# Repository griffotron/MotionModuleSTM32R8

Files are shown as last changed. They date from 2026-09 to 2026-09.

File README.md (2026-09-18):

# Introduction 
This repository contains the PCB design files and source code for the STM32 based Motion Module used in my Mechanical Display.

The Motion Module uses an STM32F103R8 microcontroller to run 14 Trinamic TMC2209 stepper drivers. It recieves motor movement commands via CAN Bus from the ESP32 based Motion Controller. Please see the related repos for the [ESP32 Controller](https://github.com/griffotron/MotionControllerESP32) and [CAD Designs](https://github.com/griffotron/MechanicalDisplayCAD).

# Build Video
Click below to watch the full build video on YouTube
Watch the video (https://www.youtube.com/watch?v=k-LaMbClWiI)

# Getting Started

## PCB
You'll need at least KiCad 8 to view and modify the PCB design files. The `PCB/production` folder contains files suitable for production with JLC PCB, including a zip containing the Gerbers for fabrication and `bom.csv` and `positions.csv` for SMT assembly. The `bom.csv` uses components from LCSC.com. If any components are no longer be available/out of stock you'll need to select an alternative.

## Code
The code uses PlatformIO (I used the VSCode plugin) and the Arduino framework.

CAN Bus library is from https://github.com/pazi88/CANBus

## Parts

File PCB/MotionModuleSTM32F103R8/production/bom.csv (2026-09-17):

Designator | Footprint | Quantity | Value | LCSC Part #
C1, C10, C101, C103, C106, C107, C109, C11, C111, C114, C115, C117, C119, C12, C122, C123, C125, C127, C13, C18, C19, C21, C23, C26, C27, C29, C31, C34, C35, C37, C39, C42, C43, C45, C47, C5, C50, C51, C53, C55, C58, C59, C61, C63, C66, C67, C69, C7, C71, C74, C75, C77, C79, C8, C82, C83, C85, C87, C9, C90, C91, C93, C95, C98, C99 | 0603 | 65 | 0.1u 50V | C14663
C100, C108, C116, C124, C20, C28, C36, C44, C52, C60, C68, C76, C84, C92 | 0603 | 14 | 22n 50V | C21122
C102, C110, C118, C126, C22, C30, C38, C46, C54, C6, C62, C70, C78, C86, C94 | 0603 | 15 | 4.7u 10v | C19666
C104, C105, C112, C113, C120, C121, C16, C17, C24, C25, C32, C33, C40, C41, C48, C49, C56, C57, C64, C65, C72, C73, C80, C81, C88, C89, C96, C97 | 0603 | 28 | 10u 35V | C96446
C128, C129, C130, C131, C132, C133, C134, C135, C136, C137, C138, C139, C140, C141, C2 | CP_Elec_5x5.4 | 15 | 47u | C4747958
C14, C15 | 0603 | 2 | 30pf | C1658
C3 | CP_Elec_6.3x4.9 | 1 | 100u | C22395169
C4 | CP_Elec_4x5.7 | 1 | 10u | C5155338
D1 | 0603 | 1 | 12v PWR LED | C5179611
D2 | 0603 | 1 | 3.3v PWR LED | C5355429
D3 | 0603 | 1 | STATUS LED | C19171301
J1, J22 | PinHeader_1x02_P2.54mm_Vertical | 2 | Screw_Terminal_01x02
J10, J12, J14, J16, J18, J20, J23, J24, J25, J27, J29, J4, J6, J8 | PinHeader_1x04_P2.54mm_Vertical | 14 | Conn_01x04_Pin
J11, J13, J15, J17, J19, J21, J26, J28, J3, J30, J32, J5, J7, J9 | JST_PH_B4B-PH-K_1x04_P2.00mm_Vertical | 14 | Conn_01x04_Pin | C131334
J2 | PinHeader_1x05_P2.54mm_Vertical | 1 | Conn_01x05_Pin
R1 | 0603 | 1 | 2k | C22975
R10, R11, R12, R13, R14, R15, R16, R17, R18, R19, R20, R21, R22, R23, R24, R25, R26, R27, R28, R29, R30, R31, R32, R5, R6, R7, R8, R9 | 1206 | 28 | 0R11 | C309533
R2, R4 | 0603 | 2 | 500 | C23193
R3 | 0603 | 1 | 10k | C25804
R33, R34, R35, R36, R37, R38, R39, R40, R41, R42, R43, R44, R45, R46 | 0603 | 14 | R
SW1 | SW_Tactile_SPST_NO_Straight_CK_PTS636Sx25SMTRLFS | 1 | RESET | C2689642
TP1 | TestPoint_Pad_D2.0mm | 1 | BOOT0 TP
TP16 | TestPoint_Pad_D2.0mm | 1 | MS1
TP2 | TestPoint_Pad_D2.0mm | 1 | MS2
TP30 | TestPoint_Pad_D2.0mm | 1 | DIAG
TP44 | TestPoint_Pad_D2.0mm | 1 | UART
TP58 | TestPoint_Pad_D2.0mm | 1 | INDEX
U1 | SOT-223-3_TabPin2 | 1 | AMS1117-3.3 | C5250992
U10, U11, U12, U13, U14, U15, U16, U17, U4, U5, U6, U7, U8, U9 | QFN28_5X5_TRI | 14 | TMC2209 | C465949
U2 | SOIC-8_3.9x4.9mm_P1.27mm | 1 | MCP2562-E-SN | C191417
U3 | LQFP-64_10x10mm_P0.5mm | 1 | STM32F103R8Tx | C46034
Y1 | Crystal_SMD_5032-2Pin_5.0x3.2mm | 1 | Crystal | C115962

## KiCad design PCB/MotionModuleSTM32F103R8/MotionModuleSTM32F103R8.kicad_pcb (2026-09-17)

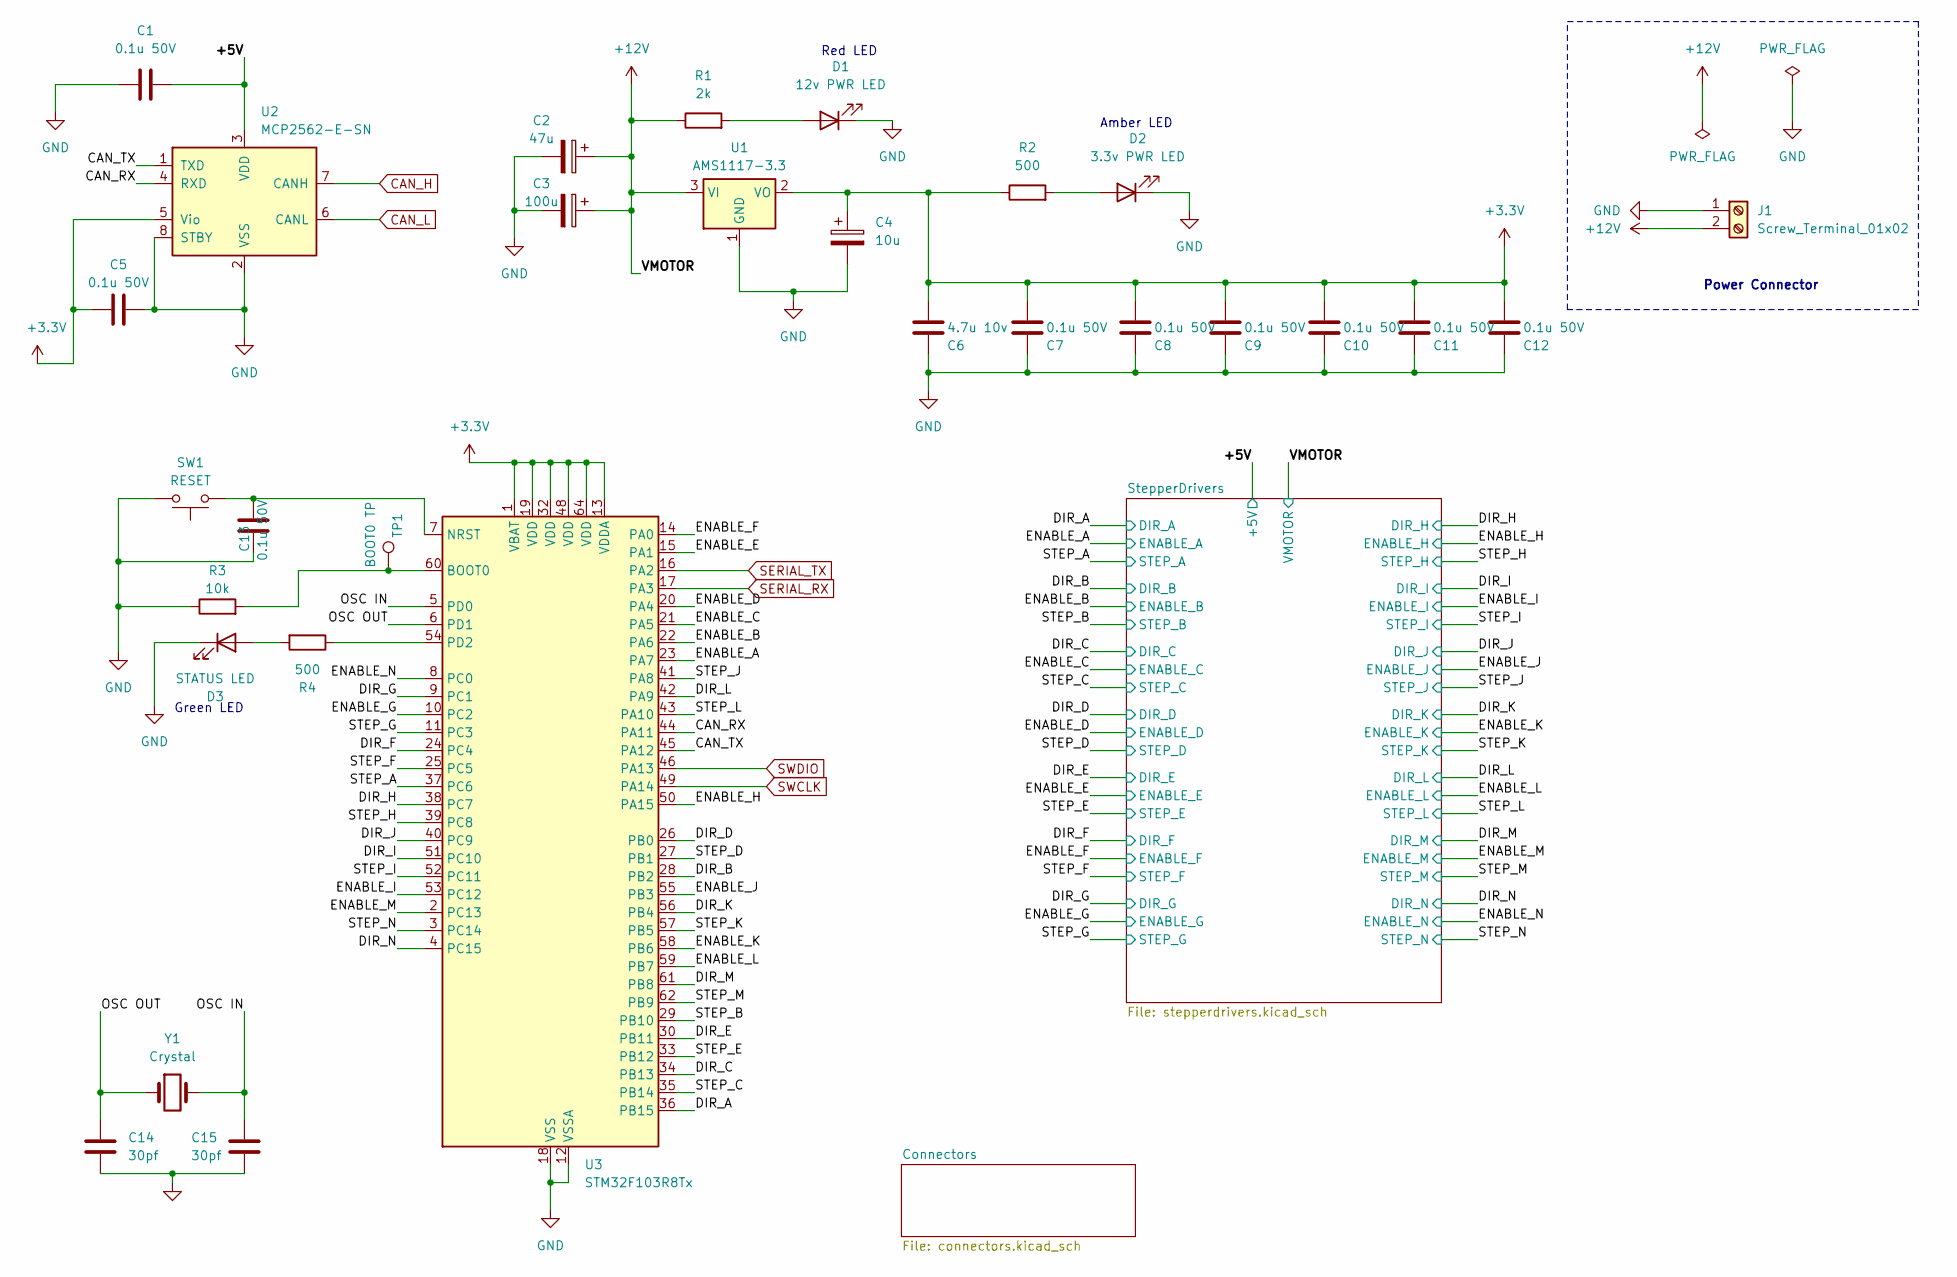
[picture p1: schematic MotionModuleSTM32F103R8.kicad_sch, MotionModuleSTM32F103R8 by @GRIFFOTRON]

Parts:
C1, C5, C7, C8, C9, C10, C11, C12, C13: 0.1u 50V; C_0603_1608Metric; MPN CC0603KRX7R9BB104; LCSC C14663
C2: 47u; CP_Elec_5x5.4; MPN RST47UF25V035; LCSC C4747958
C3: 100u; CP_Elec_6.3x4.9; MPN SPT1EM101E05TRVZC; LCSC C22395169
C4: 10u; CP_Elec_4x5.7; MPN FZ10UF25V90RV0144; DigiKey 732-6401-1-ND (Poly)
C6: 4.7u 10v; C_0603_1608Metric; MPN CL10A475KO8NNNC; LCSC C19666
C14, C15: 30pf; C_0603_1608Metric; MPN 0603CG300J500NT; LCSC C1658
D1: 12v PWR LED; LED_0603_1608Metric; MPN A-SP192YR6C-A02-4T; DigiKey 732-4978-1-ND
D2: 3.3v PWR LED; LED_0603_1608Metric; MPN A-SP192GS1C-A01-4T; DigiKey 732-150060AS75000CT-ND
D3: STATUS LED; LED_0603_1608Metric; MPN A-SP192DGHC-C01-4T; DigiKey 732-4971-1-ND
J1: Screw_Terminal_01x02; PinHeader_1x02_P2.54mm_Vertical
R1: 2k; R_0603_1608Metric; MPN 0603WAF2001T5E; LCSC C22975
R2, R4: 500; R_0603_1608Metric; MPN 0603WAF5100T5E; LCSC C23193
R3: 10k; R_0603_1608Metric; MPN 0603WAF1002T5E; LCSC C25804
SW1: RESET; SW_Tactile_SPST_NO_Straight_CK_PTS636Sx25SMTRLFS; MPN PTS636SK25SMTRLFS; LCSC C2689642
TP1: BOOT0 TP; TestPoint_Pad_D2.0mm
U1: AMS1117-3.3; SOT-223-3_TabPin2; MPN AMS1117-3.3; LCSC C5250992
U2: MCP2562-E-SN; SOIC-8_3.9x4.9mm_P1.27mm; MPN MCP2562T-E/SN; LCSC C191417
U3: STM32F103R8Tx; LQFP-64_10x10mm_P0.5mm; MPN STM32F103R8T6; LCSC C46034
Y1: Crystal; Crystal_SMD_5032-2Pin_5.0x3.2mm; MPN X50328MSB2GI; LCSC C115962

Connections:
+3.3V: C4.1, C5.2, C6.1, C7.1, C8.1, C9.1, C10.1, C11.1, C12.1, R2.1, U1.2 (VO), U2.5 (Vio), U3.1 (VBAT), U3.13 (VDDA), U3.19 (VDD), U3.32 (VDD), U3.48 (VDD), U3.64 (VDD)
+12V: C2.1, C3.1, J1.2, R1.1, U1.3 (VI); also elsewhere on the board
/+5V: C1.1, U2.3 (VDD); also elsewhere on the board
/CAN_RX: U2.4 (RXD), U3.44 (PA11)
/CAN_TX: U2.1 (TXD), U3.45 (PA12)
/DIR_A: U3.36 (PB15); also elsewhere on the board
/DIR_B: U3.28 (PB2); also elsewhere on the board
/DIR_C: U3.34 (PB13); also elsewhere on the board
/DIR_D: U3.26 (PB0); also elsewhere on the board
/DIR_E: U3.30 (PB11); also elsewhere on the board
/DIR_F: U3.24 (PC4); also elsewhere on the board
/DIR_G: U3.9 (PC1); also elsewhere on the board
/DIR_H: U3.38 (PC7); also elsewhere on the board
/DIR_I: U3.51 (PC10); also elsewhere on the board
/DIR_J: U3.40 (PC9); also elsewhere on the board
/DIR_K: U3.56 (PB4); also elsewhere on the board
/DIR_L: U3.42 (PA9); also elsewhere on the board
/DIR_M: U3.61 (PB8); also elsewhere on the board
/DIR_N: U3.4 (PC15); also elsewhere on the board
/ENABLE_A: U3.23 (PA7); also elsewhere on the board
/ENABLE_B: U3.22 (PA6); also elsewhere on the board
/ENABLE_C: U3.21 (PA5); also elsewhere on the board
/ENABLE_D: U3.20 (PA4); also elsewhere on the board
/ENABLE_E: U3.15 (PA1); also elsewhere on the board
/ENABLE_F: U3.14 (PA0); also elsewhere on the board
/ENABLE_G: U3.10 (PC2); also elsewhere on the board
/ENABLE_H: U3.50 (PA15); also elsewhere on the board
/ENABLE_I: U3.53 (PC12); also elsewhere on the board
/ENABLE_J: U3.55 (PB3); also elsewhere on the board
/ENABLE_K: U3.58 (PB6); also elsewhere on the board
/ENABLE_L: U3.59 (PB7); also elsewhere on the board
/ENABLE_M: U3.2 (PC13); also elsewhere on the board
/ENABLE_N: U3.8 (PC0); also elsewhere on the board
/OSC IN: C15.1, U3.5 (PD0), Y1.2
/OSC OUT: C14.2, U3.6 (PD1), Y1.1
/STEP_A: U3.37 (PC6); also elsewhere on the board
/STEP_B: U3.29 (PB10); also elsewhere on the board
/STEP_C: U3.35 (PB14); also elsewhere on the board
/STEP_D: U3.27 (PB1); also elsewhere on the board
/STEP_E: U3.33 (PB12); also elsewhere on the board
/STEP_F: U3.25 (PC5); also elsewhere on the board
/STEP_G: U3.11 (PC3); also elsewhere on the board
/STEP_H: U3.39 (PC8); also elsewhere on the board
/STEP_I: U3.52 (PC11); also elsewhere on the board
/STEP_J: U3.41 (PA8); also elsewhere on the board
/STEP_K: U3.57 (PB5); also elsewhere on the board
/STEP_L: U3.43 (PA10); also elsewhere on the board
/STEP_M: U3.62 (PB9); also elsewhere on the board
/STEP_N: U3.3 (PC14); also elsewhere on the board
CAN_H: U2.7 (CANH); also elsewhere on the board
CAN_L: U2.6 (CANL); also elsewhere on the board
GND: C1.2, C2.2, C3.2, C4.2, C5.1, C6.2, C7.2, C8.2, C9.2, C10.2, C11.2, C12.2, C13.2, C14.1, C15.2, D1.1 (K), D2.1 (K), D3.1 (K), J1.1, R3.1, SW1.2, U1.1 (GND), U2.2 (VSS), U2.8 (STBY), U3.12 (VSSA), U3.18 (VSS), U3.31 (VSS), U3.47 (VSS), U3.63 (VSS); also elsewhere on the board
unnamed: D1.2 (A), R1.2
unnamed: D2.2 (A), R2.2
unnamed: D3.2 (A), R4.2
unnamed: R3.2, TP1.1, U3.60 (BOOT0)
unnamed: C13.1, SW1.1, U3.7 (NRST)
unnamed: R4.1, U3.54 (PD2)
SERIAL_RX: U3.17 (PA3); also elsewhere on the board
SERIAL_TX: U3.16 (PA2); also elsewhere on the board
SWCLK: U3.49 (PA14); also elsewhere on the board
SWDIO: U3.46 (PA13); also elsewhere on the board

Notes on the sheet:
Green LED
Power Connector
Amber LED
Red LED

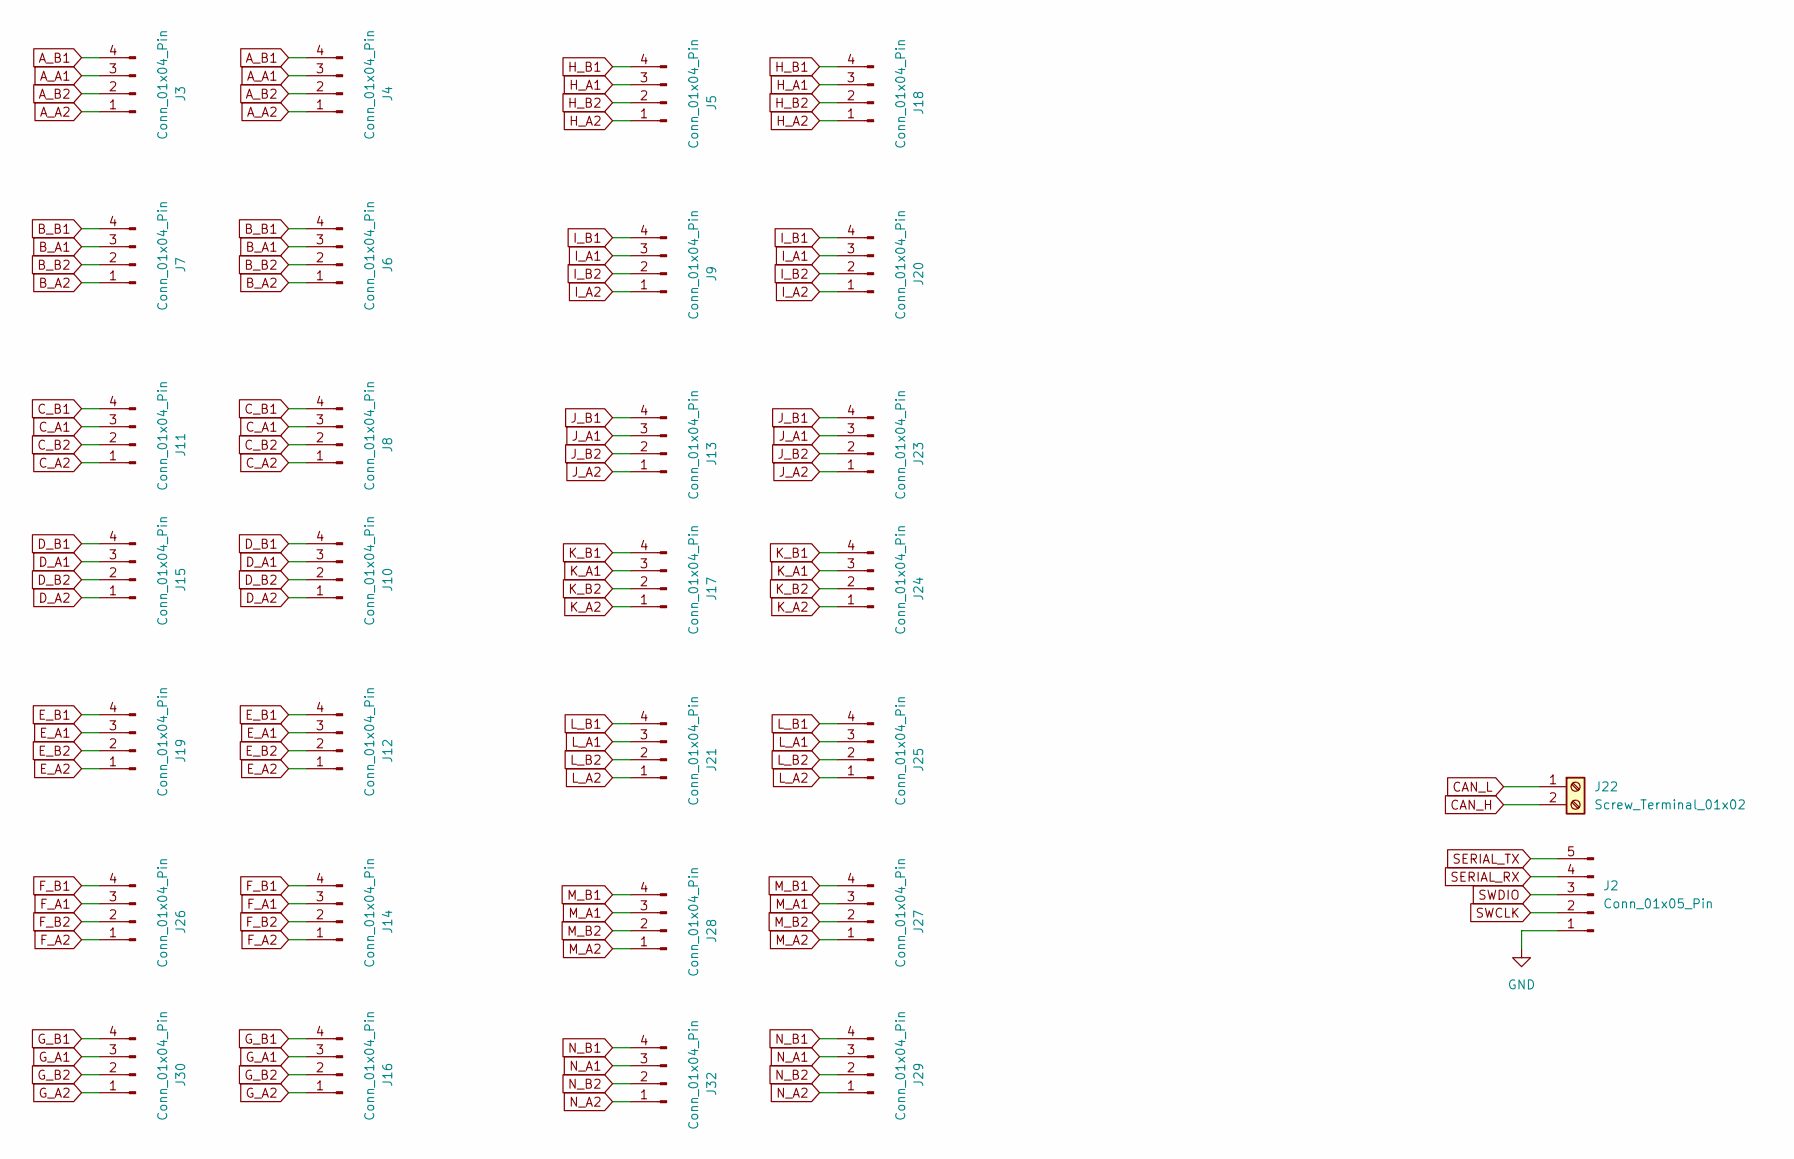
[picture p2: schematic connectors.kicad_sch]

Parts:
J2: Conn_01x05_Pin; PinHeader_1x05_P2.54mm_Vertical
J3, J5, J7, J9, J11, J13, J15, J17, J19, J21, J26, J28, J30, J32: Conn_01x04_Pin; JST_PH_B4B-PH-K_1x04_P2.00mm_Vertical; MPN B4B-PH-K-S(LF)(SN); LCSC C131334
J4, J6, J8, J10, J12, J14, J16, J18, J20, J23, J24, J25, J27, J29: Conn_01x04_Pin; PinHeader_1x04_P2.54mm_Vertical
J22: Screw_Terminal_01x02; PinHeader_1x02_P2.54mm_Vertical

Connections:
A_A1: J3.3, J4.3; also elsewhere on the board
A_A2: J3.1, J4.1; also elsewhere on the board
A_B1: J3.4, J4.4; also elsewhere on the board
A_B2: J3.2, J4.2; also elsewhere on the board
B_A1: J6.3, J7.3; also elsewhere on the board
B_A2: J6.1, J7.1; also elsewhere on the board
B_B1: J6.4, J7.4; also elsewhere on the board
B_B2: J6.2, J7.2; also elsewhere on the board
CAN_H: J22.2; also elsewhere on the board
CAN_L: J22.1; also elsewhere on the board
C_A1: J8.3, J11.3; also elsewhere on the board
C_A2: J8.1, J11.1; also elsewhere on the board
C_B1: J8.4, J11.4; also elsewhere on the board
C_B2: J8.2, J11.2; also elsewhere on the board
D_A1: J10.3, J15.3; also elsewhere on the board
D_A2: J10.1, J15.1; also elsewhere on the board
D_B1: J10.4, J15.4; also elsewhere on the board
D_B2: J10.2, J15.2; also elsewhere on the board
E_A1: J12.3, J19.3; also elsewhere on the board
E_A2: J12.1, J19.1; also elsewhere on the board
E_B1: J12.4, J19.4; also elsewhere on the board
E_B2: J12.2, J19.2; also elsewhere on the board
F_A1: J14.3, J26.3; also elsewhere on the board
F_A2: J14.1, J26.1; also elsewhere on the board
F_B1: J14.4, J26.4; also elsewhere on the board
F_B2: J14.2, J26.2; also elsewhere on the board
GND: J2.1; also elsewhere on the board
G_A1: J16.3, J30.3; also elsewhere on the board
G_A2: J16.1, J30.1; also elsewhere on the board
G_B1: J16.4, J30.4; also elsewhere on the board
G_B2: J16.2, J30.2; also elsewhere on the board
H_A1: J5.3, J18.3; also elsewhere on the board
H_A2: J5.1, J18.1; also elsewhere on the board
H_B1: J5.4, J18.4; also elsewhere on the board
H_B2: J5.2, J18.2; also elsewhere on the board
I_A1: J9.3, J20.3; also elsewhere on the board
I_A2: J9.1, J20.1; also elsewhere on the board
I_B1: J9.4, J20.4; also elsewhere on the board
I_B2: J9.2, J20.2; also elsewhere on the board
J_A1: J13.3, J23.3; also elsewhere on the board
J_A2: J13.1, J23.1; also elsewhere on the board
J_B1: J13.4, J23.4; also elsewhere on the board
J_B2: J13.2, J23.2; also elsewhere on the board
K_A1: J17.3, J24.3; also elsewhere on the board
K_A2: J17.1, J24.1; also elsewhere on the board
K_B1: J17.4, J24.4; also elsewhere on the board
K_B2: J17.2, J24.2; also elsewhere on the board
L_A1: J21.3, J25.3; also elsewhere on the board
L_A2: J21.1, J25.1; also elsewhere on the board
L_B1: J21.4, J25.4; also elsewhere on the board
L_B2: J21.2, J25.2; also elsewhere on the board
M_A1: J27.3, J28.3; also elsewhere on the board
M_A2: J27.1, J28.1; also elsewhere on the board
M_B1: J27.4, J28.4; also elsewhere on the board
M_B2: J27.2, J28.2; also elsewhere on the board
N_A1: J29.3, J32.3; also elsewhere on the board
N_A2: J29.1, J32.1; also elsewhere on the board
N_B1: J29.4, J32.4; also elsewhere on the board
N_B2: J29.2, J32.2; also elsewhere on the board
SERIAL_RX: J2.4; also elsewhere on the board
SERIAL_TX: J2.5; also elsewhere on the board
SWCLK: J2.2; also elsewhere on the board
SWDIO: J2.3; also elsewhere on the board

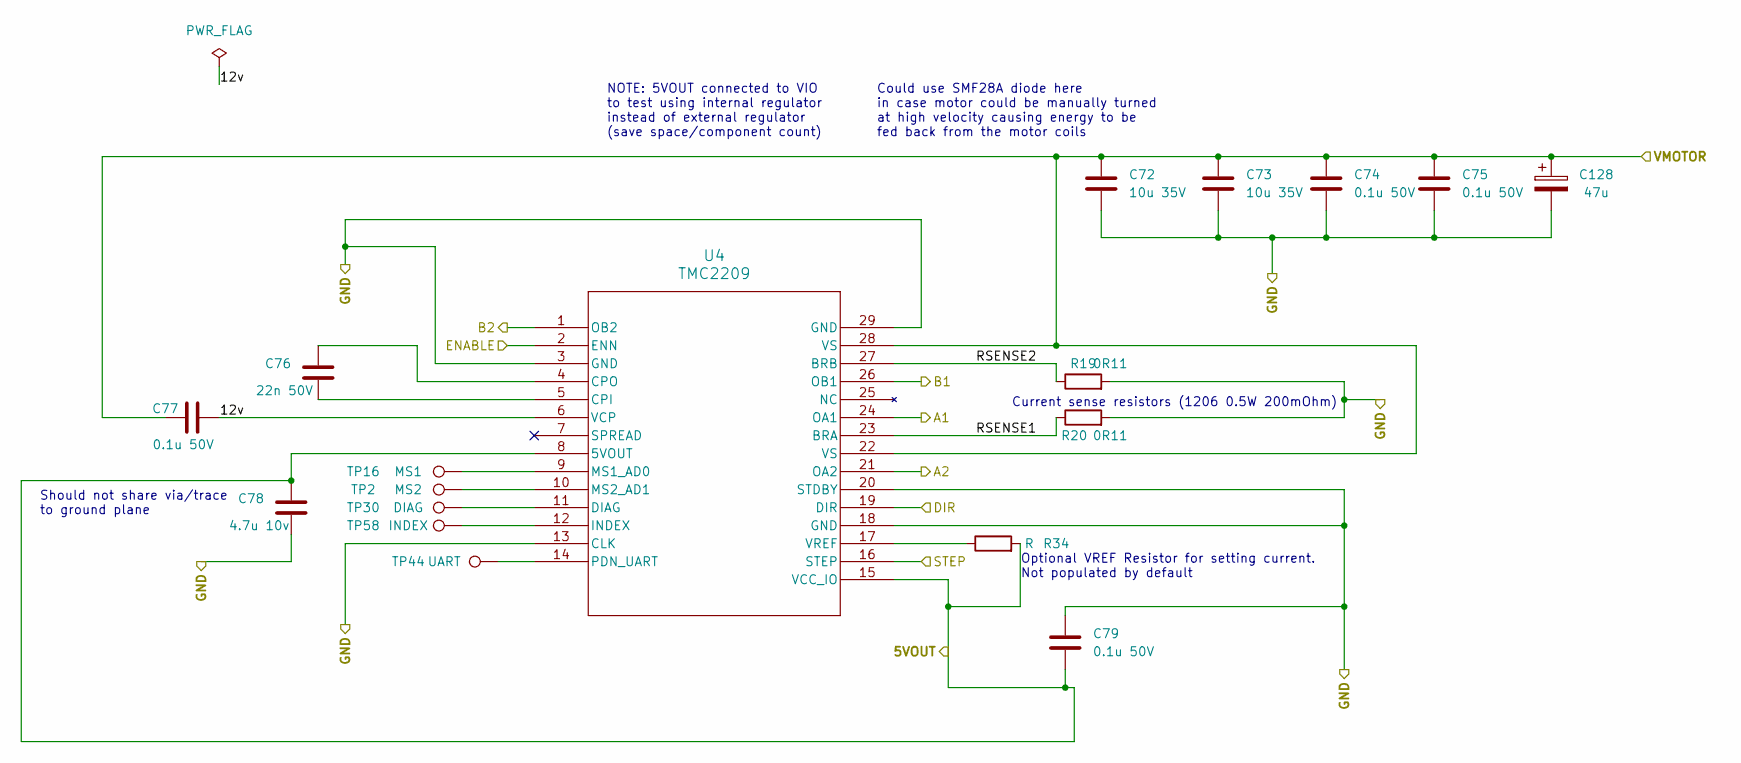
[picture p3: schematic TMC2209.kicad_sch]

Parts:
C72, C73: 10u 35V; C_0603_1608Metric; MPN CL10A106MA8NRNC; LCSC C96446
C74, C75, C77, C79: 0.1u 50V; C_0603_1608Metric; MPN CC0603KRX7R9BB104; LCSC C14663
C76: 22n 50V; C_0603_1608Metric; MPN CL10B223KB8NNNC; LCSC C21122
C78: 4.7u 10v; C_0603_1608Metric; MPN CL10A475KO8NNNC; LCSC C19666
C128: 47u; CP_Elec_5x5.4; MPN RST47UF25V035; LCSC C4747958
R19, R20: 0R11; R_1206_3216Metric; MPN PT1206FR-7W0R2L; DigiKey P19309CT-ND (Panasonic 0805)
R34: R; R_0603_1608Metric_Pad0.98x0.95mm_HandSolder
TP2: MS2; TestPoint_Pad_D2.0mm
TP16: MS1; TestPoint_Pad_D2.0mm
TP30: DIAG; TestPoint_Pad_D2.0mm
TP44: UART; TestPoint_Pad_D2.0mm
TP58: INDEX; TestPoint_Pad_D2.0mm
U4: TMC2209; QFN28_5X5_TRI; MPN TMC2209-LA-T; LCSC C465949

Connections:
+12V: C72.1, C73.1, C74.1, C75.1, C77.2, C128.1, U4.22 (VS), U4.28 (VS); also elsewhere on the board
/DIR_A: U4.19 (DIR); also elsewhere on the board
/ENABLE_A: U4.2 (ENN); also elsewhere on the board
/STEP_A: U4.16 (STEP); also elsewhere on the board
A_A1: U4.24 (OA1); also elsewhere on the board
A_A2: U4.21 (OA2); also elsewhere on the board
A_B1: U4.26 (OB1); also elsewhere on the board
A_B2: U4.1 (OB2); also elsewhere on the board
GND: C72.2, C73.2, C74.2, C75.2, C78.2, C79.2, C128.2, R19.2, R20.2, U4.3 (GND), U4.13 (CLK), U4.18 (GND), U4.20 (STDBY), U4.29 (GND); also elsewhere on the board
unnamed: TP30.1, U4.11 (DIAG)
unnamed: TP58.1, U4.12 (INDEX)
unnamed: TP16.1, U4.9 (MS1_AD0)
unnamed: TP2.1, U4.10 (MS2_AD1)
unnamed: TP44.1, U4.14 (PDN_UART)

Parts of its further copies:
C16, C17, C24, C25, C32, C33, C40, C41, C48, C49, C56, C57, C64, C65, C80, C81, C88, C89, C96, C97, C104, C105, C112, C113, C120, C121: 10u 35V; C_0603_1608Metric; MPN CL10A106MA8NRNC; LCSC C96446
C18, C19, C21, C23, C26, C27, C29, C31, C34, C35, C37, C39, C42, C43, C45, C47, C50, C51, C53, C55, C58, C59, C61, C63, C66, C67, C69, C71, C82, C83, C85, C87, C90, C91, C93, C95, C98, C99, C101, C103, C106, C107, C109, C111, C114, C115, C117, C119, C122, C123, C125, C127: 0.1u 50V; C_0603_1608Metric; MPN CC0603KRX7R9BB104; LCSC C14663
C20, C28, C36, C44, C52, C60, C68, C84, C92, C100, C108, C116, C124: 22n 50V; C_0603_1608Metric; MPN CL10B223KB8NNNC; LCSC C21122
C22, C30, C38, C46, C54, C62, C70, C86, C94, C102, C110, C118, C126: 4.7u 10v; C_0603_1608Metric; MPN CL10A475KO8NNNC; LCSC C19666
C129, C130, C131, C132, C133, C134, C135, C136, C137, C138, C139, C140, C141: 47u; CP_Elec_5x5.4; MPN RST47UF25V035; LCSC C4747958
R5, R6, R7, R8, R9, R10, R11, R12, R13, R14, R15, R16, R17, R18, R21, R22, R23, R24, R25, R26, R27, R28, R29, R30, R31, R32: 0R11; R_1206_3216Metric; MPN PT1206FR-7W0R2L; DigiKey P19309CT-ND (Panasonic 0805)
R33, R35, R36, R37, R38, R39, R40, R41, R42, R43, R44, R45, R46: R; R_0603_1608Metric_Pad0.98x0.95mm_HandSolder
U5, U6, U7, U8, U9, U10, U11, U12, U13, U14, U15, U16, U17: TMC2209; QFN28_5X5_TRI; MPN TMC2209-LA-T; LCSC C465949

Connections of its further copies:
+12V: C16.1, C17.1, C18.1, C19.1, C21.2, C24.1, C25.1, C26.1, C27.1, C29.2, C32.1, C33.1, C34.1, C35.1, C37.2, C40.1, C41.1, C42.1, C43.1, C45.2, C48.1, C49.1, C50.1, C51.1, C53.2, C56.1, C57.1, C58.1, C59.1, C61.2, C64.1, C65.1, C66.1, C67.1, C69.2, C80.1, C81.1, C82.1, C83.1, C85.2, C88.1, C89.1, C90.1, C91.1, C93.2, C96.1, C97.1, C98.1, C99.1, C101.2, C104.1, C105.1, C106.1, C107.1, C109.2, C112.1, C113.1, C114.1, C115.1, C117.2, C120.1, C121.1, C122.1, C123.1, C125.2, C129.1, C130.1, C131.1, C132.1, C133.1, C134.1, C135.1, C136.1, C137.1, C138.1, C139.1, C140.1, C141.1, U5.22 (VS), U5.28 (VS), U6.22 (VS), U6.28 (VS), U7.22 (VS), U7.28 (VS), U8.22 (VS), U8.28 (VS), U9.22 (VS), U9.28 (VS), U10.22 (VS), U10.28 (VS), U11.22 (VS), U11.28 (VS), U12.22 (VS), U12.28 (VS), U13.22 (VS), U13.28 (VS), U14.22 (VS), U14.28 (VS), U15.22 (VS), U15.28 (VS), U16.22 (VS), U16.28 (VS), U17.22 (VS), U17.28 (VS); also elsewhere on the board
/+5V: C126.1, C127.1, R46.2, U17.8 (5VOUT), U17.15 (VCC_IO); also elsewhere on the board
/DIR_B: U8.19 (DIR); also elsewhere on the board
/DIR_C: U9.19 (DIR); also elsewhere on the board
/DIR_D: U5.19 (DIR); also elsewhere on the board
/DIR_E: U10.19 (DIR); also elsewhere on the board
/DIR_F: U7.19 (DIR); also elsewhere on the board
/DIR_G: U6.19 (DIR); also elsewhere on the board
/DIR_H: U11.19 (DIR); also elsewhere on the board
/DIR_I: U12.19 (DIR); also elsewhere on the board
/DIR_J: U13.19 (DIR); also elsewhere on the board
/DIR_K: U14.19 (DIR); also elsewhere on the board
/DIR_L: U15.19 (DIR); also elsewhere on the board
/DIR_M: U16.19 (DIR); also elsewhere on the board
/DIR_N: U17.19 (DIR); also elsewhere on the board
/ENABLE_B: U8.2 (ENN); also elsewhere on the board
/ENABLE_C: U9.2 (ENN); also elsewhere on the board
/ENABLE_D: U5.2 (ENN); also elsewhere on the board
/ENABLE_E: U10.2 (ENN); also elsewhere on the board
/ENABLE_F: U7.2 (ENN); also elsewhere on the board
/ENABLE_G: U6.2 (ENN); also elsewhere on the board
/ENABLE_H: U11.2 (ENN); also elsewhere on the board
/ENABLE_I: U12.2 (ENN); also elsewhere on the board
/ENABLE_J: U13.2 (ENN); also elsewhere on the board
/ENABLE_K: U14.2 (ENN); also elsewhere on the board
/ENABLE_L: U15.2 (ENN); also elsewhere on the board
/ENABLE_M: U16.2 (ENN); also elsewhere on the board
/ENABLE_N: U17.2 (ENN); also elsewhere on the board
/STEP_B: U8.16 (STEP); also elsewhere on the board
/STEP_C: U9.16 (STEP); also elsewhere on the board
/STEP_D: U5.16 (STEP); also elsewhere on the board
/STEP_E: U10.16 (STEP); also elsewhere on the board
/STEP_F: U7.16 (STEP); also elsewhere on the board
/STEP_G: U6.16 (STEP); also elsewhere on the board
/STEP_H: U11.16 (STEP); also elsewhere on the board
/STEP_I: U12.16 (STEP); also elsewhere on the board
/STEP_J: U13.16 (STEP); also elsewhere on the board
/STEP_K: U14.16 (STEP); also elsewhere on the board
/STEP_L: U15.16 (STEP); also elsewhere on the board
/STEP_M: U16.16 (STEP); also elsewhere on the board
/STEP_N: U17.16 (STEP); also elsewhere on the board
/StepperDrivers/TMC2209-B/5VOUT: C54.1, C55.1, R37.2, U8.8 (5VOUT), U8.15 (VCC_IO)
/StepperDrivers/TMC2209-B/12v: C53.1, U8.6 (VCP)
/StepperDrivers/TMC2209-B/RSENSE1: R14.1, U8.23 (BRA)
/StepperDrivers/TMC2209-B/RSENSE2: R13.1, U8.27 (BRB)
/StepperDrivers/TMC2209-C/5VOUT: C62.1, C63.1, R38.2, U9.8 (5VOUT), U9.15 (VCC_IO)
/StepperDrivers/TMC2209-C/12v: C61.1, U9.6 (VCP)
/StepperDrivers/TMC2209-C/RSENSE1: R16.1, U9.23 (BRA)
/StepperDrivers/TMC2209-C/RSENSE2: R15.1, U9.27 (BRB)
/StepperDrivers/TMC2209-D/12v: C29.1, U5.6 (VCP)
/StepperDrivers/TMC2209-D/RSENSE1: R8.1, U5.23 (BRA)
/StepperDrivers/TMC2209-D/RSENSE2: R7.1, U5.27 (BRB)
/StepperDrivers/TMC2209-E/5VOUT: C70.1, C71.1, R39.2, U10.8 (5VOUT), U10.15 (VCC_IO)
/StepperDrivers/TMC2209-E/12v: C69.1, U10.6 (VCP)
/StepperDrivers/TMC2209-E/RSENSE1: R18.1, U10.23 (BRA)
/StepperDrivers/TMC2209-E/RSENSE2: R17.1, U10.27 (BRB)
/StepperDrivers/TMC2209-F/5VOUT: C46.1, C47.1, R36.2, U7.8 (5VOUT), U7.15 (VCC_IO)
/StepperDrivers/TMC2209-F/12v: C45.1, U7.6 (VCP)
/StepperDrivers/TMC2209-F/RSENSE1: R12.1, U7.23 (BRA)
/StepperDrivers/TMC2209-F/RSENSE2: R11.1, U7.27 (BRB)
/StepperDrivers/TMC2209-G/5VOUT: C38.1, C39.1, R35.2, U6.8 (5VOUT), U6.15 (VCC_IO)
/StepperDrivers/TMC2209-G/12v: C37.1, U6.6 (VCP)
/StepperDrivers/TMC2209-G/RSENSE1: R10.1, U6.23 (BRA)
/StepperDrivers/TMC2209-G/RSENSE2: R9.1, U6.27 (BRB)
/StepperDrivers/TMC2209-I/5VOUT: C86.1, C87.1, R41.2, U12.8 (5VOUT), U12.15 (VCC_IO)
/StepperDrivers/TMC2209-I/12v: C85.1, U12.6 (VCP)
/StepperDrivers/TMC2209-I/RSENSE1: R22.1, U12.23 (BRA)
/StepperDrivers/TMC2209-I/RSENSE2: R21.1, U12.27 (BRB)
/StepperDrivers/TMC2209-J/5VOUT: C94.1, C95.1, R42.2, U13.8 (5VOUT), U13.15 (VCC_IO)
/StepperDrivers/TMC2209-J/12v: C93.1, U13.6 (VCP)
/StepperDrivers/TMC2209-J/RSENSE1: R24.1, U13.23 (BRA)
/StepperDrivers/TMC2209-J/RSENSE2: R23.1, U13.27 (BRB)
/StepperDrivers/TMC2209-K/5VOUT: C102.1, C103.1, R43.2, U14.8 (5VOUT), U14.15 (VCC_IO)
/StepperDrivers/TMC2209-K/12v: C101.1, U14.6 (VCP)
/StepperDrivers/TMC2209-K/RSENSE1: R26.1, U14.23 (BRA)
/StepperDrivers/TMC2209-K/RSENSE2: R25.1, U14.27 (BRB)
/StepperDrivers/TMC2209-L/5VOUT: C110.1, C111.1, R44.2, U15.8 (5VOUT), U15.15 (VCC_IO)
/StepperDrivers/TMC2209-L/12v: C109.1, U15.6 (VCP)
/StepperDrivers/TMC2209-L/RSENSE1: R28.1, U15.23 (BRA)
/StepperDrivers/TMC2209-L/RSENSE2: R27.1, U15.27 (BRB)
/StepperDrivers/TMC2209-M/5VOUT: C118.1, C119.1, R45.2, U16.8 (5VOUT), U16.15 (VCC_IO)
/StepperDrivers/TMC2209-M/12v: C117.1, U16.6 (VCP)
/StepperDrivers/TMC2209-M/RSENSE1: R30.1, U16.23 (BRA)
/StepperDrivers/TMC2209-M/RSENSE2: R29.1, U16.27 (BRB)
/StepperDrivers/TMC2209-N/12v: C125.1, U17.6 (VCP)
/StepperDrivers/TMC2209-N/RSENSE1: R32.1, U17.23 (BRA)
/StepperDrivers/TMC2209-N/RSENSE2: R31.1, U17.27 (BRB)
B_A1: U8.24 (OA1); also elsewhere on the board
B_A2: U8.21 (OA2); also elsewhere on the board
B_B1: U8.26 (OB1); also elsewhere on the board
B_B2: U8.1 (OB2); also elsewhere on the board
C_A1: U9.24 (OA1); also elsewhere on the board
C_A2: U9.21 (OA2); also elsewhere on the board
C_B1: U9.26 (OB1); also elsewhere on the board
C_B2: U9.1 (OB2); also elsewhere on the board
D_A1: U5.24 (OA1); also elsewhere on the board
D_A2: U5.21 (OA2); also elsewhere on the board
D_B1: U5.26 (OB1); also elsewhere on the board
D_B2: U5.1 (OB2); also elsewhere on the board
E_A1: U10.24 (OA1); also elsewhere on the board
E_A2: U10.21 (OA2); also elsewhere on the board
E_B1: U10.26 (OB1); also elsewhere on the board
E_B2: U10.1 (OB2); also elsewhere on the board
F_A1: U7.24 (OA1); also elsewhere on the board
F_A2: U7.21 (OA2); also elsewhere on the board
F_B1: U7.26 (OB1); also elsewhere on the board
F_B2: U7.1 (OB2); also elsewhere on the board
GND: C16.2, C17.2, C18.2, C19.2, C22.2, C23.2, C24.2, C25.2, C26.2, C27.2, C30.2, C31.2, C32.2, C33.2, C34.2, C35.2, C38.2, C39.2, C40.2, C41.2, C42.2, C43.2, C46.2, C47.2, C48.2, C49.2, C50.2, C51.2, C54.2, C55.2, C56.2, C57.2, C58.2, C59.2, C62.2, C63.2, C64.2, C65.2, C66.2, C67.2, C70.2, C71.2, C80.2, C81.2, C82.2, C83.2, C86.2, C87.2, C88.2, C89.2, C90.2, C91.2, C94.2, C95.2, C96.2, C97.2, C98.2, C99.2, C102.2, C103.2, C104.2, C105.2, C106.2, C107.2, C110.2, C111.2, C112.2, C113.2, C114.2, C115.2, C118.2, C119.2, C120.2, C121.2, C122.2, C123.2, C126.2, C127.2, C129.2, C130.2, C131.2, C132.2, C133.2, C134.2, C135.2, C136.2, C137.2, C138.2, C139.2, C140.2, C141.2, R5.2, R6.2, R7.2, R8.2, R9.2, R10.2, R11.2, R12.2, R13.2, R14.2, R15.2, R16.2, R17.2, R18.2, R21.2, R22.2, R23.2, R24.2, R25.2, R26.2, R27.2, R28.2, R29.2, R30.2, R31.2, R32.2, U5.3 (GND), U5.13 (CLK), U5.18 (GND), U5.20 (STDBY), U5.29 (GND), U6.3 (GND), U6.13 (CLK), U6.18 (GND), U6.20 (STDBY), U6.29 (GND), U7.3 (GND), U7.13 (CLK), U7.18 (GND), U7.20 (STDBY), U7.29 (GND), U8.3 (GND), U8.13 (CLK), U8.18 (GND), U8.20 (STDBY), U8.29 (GND), U9.3 (GND), U9.13 (CLK), U9.18 (GND), U9.20 (STDBY), U9.29 (GND), U10.3 (GND), U10.13 (CLK), U10.18 (GND), U10.20 (STDBY), U10.29 (GND), U11.3 (GND), U11.13 (CLK), U11.18 (GND), U11.20 (STDBY), U11.29 (GND), U12.3 (GND), U12.13 (CLK), U12.18 (GND), U12.20 (STDBY), U12.29 (GND), U13.3 (GND), U13.13 (CLK), U13.18 (GND), U13.20 (STDBY), U13.29 (GND), U14.3 (GND), U14.13 (CLK), U14.18 (GND), U14.20 (STDBY), U14.29 (GND), U15.3 (GND), U15.13 (CLK), U15.18 (GND), U15.20 (STDBY), U15.29 (GND), U16.3 (GND), U16.13 (CLK), U16.18 (GND), U16.20 (STDBY), U16.29 (GND), U17.3 (GND), U17.13 (CLK), U17.18 (GND), U17.20 (STDBY), U17.29 (GND); also elsewhere on the board
G_A1: U6.24 (OA1); also elsewhere on the board
G_A2: U6.21 (OA2); also elsewhere on the board
G_B1: U6.26 (OB1); also elsewhere on the board
G_B2: U6.1 (OB2); also elsewhere on the board
H_A1: U11.24 (OA1); also elsewhere on the board
H_A2: U11.21 (OA2); also elsewhere on the board
H_B1: U11.26 (OB1); also elsewhere on the board
H_B2: U11.1 (OB2); also elsewhere on the board
I_A1: U12.24 (OA1); also elsewhere on the board
I_A2: U12.21 (OA2); also elsewhere on the board
I_B1: U12.26 (OB1); also elsewhere on the board
I_B2: U12.1 (OB2); also elsewhere on the board
J_A1: U13.24 (OA1); also elsewhere on the board
J_A2: U13.21 (OA2); also elsewhere on the board
J_B1: U13.26 (OB1); also elsewhere on the board
J_B2: U13.1 (OB2); also elsewhere on the board
K_A1: U14.24 (OA1); also elsewhere on the board
K_A2: U14.21 (OA2); also elsewhere on the board
K_B1: U14.26 (OB1); also elsewhere on the board
K_B2: U14.1 (OB2); also elsewhere on the board
L_A1: U15.24 (OA1); also elsewhere on the board
L_A2: U15.21 (OA2); also elsewhere on the board
L_B1: U15.26 (OB1); also elsewhere on the board
L_B2: U15.1 (OB2); also elsewhere on the board
M_A1: U16.24 (OA1); also elsewhere on the board
M_A2: U16.21 (OA2); also elsewhere on the board
M_B1: U16.26 (OB1); also elsewhere on the board
M_B2: U16.1 (OB2); also elsewhere on the board
N_A1: U17.24 (OA1); also elsewhere on the board
N_A2: U17.21 (OA2); also elsewhere on the board
N_B1: U17.26 (OB1); also elsewhere on the board
N_B2: U17.1 (OB2); also elsewhere on the board
unnamed: C28.2, U5.5 (CPI)
unnamed: C28.1, U5.4 (CPO)
unnamed: C36.2, U6.5 (CPI)
unnamed: C36.1, U6.4 (CPO)
unnamed: R35.1, U6.17 (VREF)
unnamed: C44.2, U7.5 (CPI)
unnamed: C44.1, U7.4 (CPO)
unnamed: R36.1, U7.17 (VREF)
unnamed: C52.2, U8.5 (CPI)
unnamed: C52.1, U8.4 (CPO)
unnamed: R37.1, U8.17 (VREF)
unnamed: C60.2, U9.5 (CPI)
unnamed: C60.1, U9.4 (CPO)
unnamed: R38.1, U9.17 (VREF)
unnamed: C68.2, U10.5 (CPI)
unnamed: C68.1, U10.4 (CPO)
unnamed: R39.1, U10.17 (VREF)
unnamed: R40.1, U11.17 (VREF)
unnamed: C84.2, U12.5 (CPI)
unnamed: C84.1, U12.4 (CPO)
unnamed: R41.1, U12.17 (VREF)
unnamed: C92.2, U13.5 (CPI)
unnamed: C92.1, U13.4 (CPO)
unnamed: R42.1, U13.17 (VREF)
unnamed: C100.2, U14.5 (CPI)
unnamed: C100.1, U14.4 (CPO)
unnamed: R43.1, U14.17 (VREF)
unnamed: C108.2, U15.5 (CPI)
unnamed: C108.1, U15.4 (CPO)
unnamed: R44.1, U15.17 (VREF)
unnamed: C116.2, U16.5 (CPI)
unnamed: C116.1, U16.4 (CPO)
unnamed: R45.1, U16.17 (VREF)
unnamed: C124.2, U17.5 (CPI)
unnamed: C124.1, U17.4 (CPO)
unnamed: R46.1, U17.17 (VREF)

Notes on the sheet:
Could use SMF28A diode here in case motor could be manually turned at high velocity causing energy to be fed back from the motor coils
NOTE: 5VOUT connected to VIO to test using internal regulator instead of external regulator (save space/component count)
Current sense resistors (1206 0.5W 200mOhm)
Optional VREF Resistor for setting current. Not populated by default
Should not share via/trace to ground plane

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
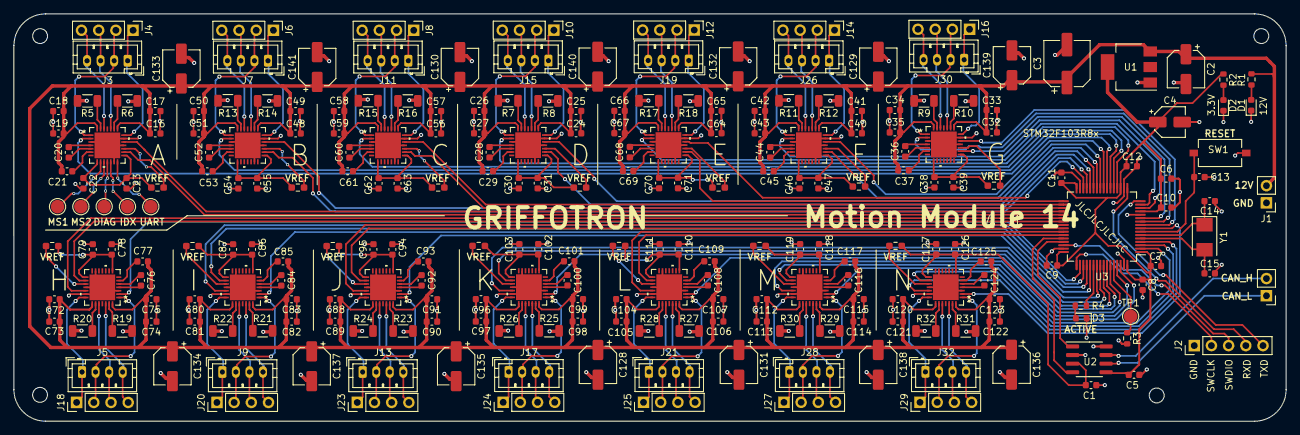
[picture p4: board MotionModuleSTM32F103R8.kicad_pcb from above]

Board: 4 copper layers, 187.9 x 60.2 mm, 246 parts (0 on the bottom side), 220 nets.

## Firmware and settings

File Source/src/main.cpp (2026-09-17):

#include <Arduino.h>
#include <SoftwareSerial.h>
#include <CANBus.h>
#include <CANReader.h>
#include <CANWriter.h>
#include <Stepper.h>
#include <CommandEngine.h>
#include <DataStructures.h>
#include <Constants.h>
#include <SystemManagement.h>
#include <CANMessageGenerator.h>
#include <HardwareTimer.h>

uint8_t engineIds[TOTAL_ENGINES] = {1, 2, 3, 4, 5, 6, 7, 8, 9, 10, 11, 12, 13, 14}; //Engine Ids are the same for all modules. Controller sends message to module and engine id within it

// Pin assignment: Enable, Direction, Step
CommandEngine engineArray[TOTAL_ENGINES] = {
  CommandEngine(engineIds[0], PA7, PB15, PC6), //A
  CommandEngine(engineIds[1], PA6, PB2, PB10), //B
  CommandEngine(engineIds[2], PA5, PB13, PB14), //C
  CommandEngine(engineIds[3], PA4, PB0, PB1), //D
  CommandEngine(engineIds[4], PA1, PB11, PB12), //E
  CommandEngine(engineIds[5], PA0, PC4, PC5), //F
  CommandEngine(engineIds[6], PC2, PC1, PC3), //G
  CommandEngine(engineIds[7], PA15, PC7, PC8), //H
  CommandEngine(engineIds[8], PC12, PC10, PC11), //I
  CommandEngine(engineIds[9], PB3, PC9, PA8), //J
  CommandEngine(engineIds[10], PB6, PB4, PB5), //K
  CommandEngine(engineIds[11], PB7, PA9, PA10), //L
  CommandEngine(engineIds[12], PC13, PB8, PB9), //M
  CommandEngine(engineIds[13], PC0, PC15, PC14) //N
};

HardwareTimer *stepTimer;
CANMessage msg;
CANBus canBus = CANBus(CAN1, DEF);
CANReader canBusReader = CANReader(canBus);
CANWriter canBusWriter = CANWriter(canBus);
SystemManagement systemMgmt = SystemManagement();
static String serialInputBuffer;
extern "C" char* sbrk(int incr);
static uint32_t _minFreeRam = UINT32_MAX;

static uint32_t getFreeRam() {
    char stackTop;
    uint32_t freeRam = (uint32_t)&stackTop - (uint32_t)sbrk(0);
    if (freeRam < _minFreeRam)
      _minFreeRam = freeRam;
    return freeRam;
}

void printStats()
{
  getFreeRam();

  // ---- Uptime -------------------------------------------------------
  const uint32_t ms      = millis();
  const uint32_t seconds = ms      / 1000UL;
  const uint32_t minutes = seconds / 60UL;
  const uint32_t hours   = minutes / 60UL;
  const uint32_t days    = hours   / 24UL;

  Serial.println(F("\n========== System Statistics =========="));
  Serial.printf("Module Id   : %u\n", MODULE_ID);
  Serial.printf("Uptime      : %lud %02lu:%02lu:%02lu.%03lu\n", days, hours % 24, minutes % 60, seconds % 60, ms % 1000);

  // ---- Memory -------------------------------------------------------
  const uint32_t freeRam = getFreeRam();
  Serial.printf("Free RAM    : %lu bytes  (min seen: %lu bytes, total: 20480 bytes)\n", freeRam, _minFreeRam);

  // ---- CPU ----------------------------------------------------------
  Serial.printf("CPU Freq    : %lu MHz\n", SystemCoreClock / 1000000UL);

  // ---- CAN ----------------------------------------------------------
  Serial.printf("CAN RX      : %lu received,  %lu remote frames dropped\n", canBusReader.getMessagesReceived(), canBusReader.getRemoteFramesDropped());
  Serial.printf("CAN TX      : %lu sent,  %lu failed\n", canBusWriter.getMessagesSent(), canBusWriter.getMessagesFailed());

  // ---- Motor status -------------------------------------------------
  Serial.println();
  Serial.println(F("Motor Status:"));
  Serial.println(F(" ID    Position    Target   Queue  Dropped  Steps Left   Total Steps  State"));
  Serial.println(F(" --  ----------  ----------  -----  -------  ----------  ------------  -------"));

  for (uint8_t i = 0; i < TOTAL_ENGINES; i++) {
      engineArray[i].printStatus();
  }

  Serial.println(F("=======================================\n"));
}

void blink(uint8_t times, int32_t durationOn, int32_t durationOff){
  uint8_t flashCount = 0;
  for(flashCount = 0; flashCount < times; flashCount++){
    digitalWrite(PIN_STATUS_LED, HIGH);
    delay(durationOn);
    digitalWrite(PIN_STATUS_LED, LOW);
    delay(durationOff);
  }
}

void reset() {
  DEBUG_PRINT.println("Resetting");
  blink(3, 100, 100);
  NVIC_SystemReset();
}

void runSelfTest(){
  DEBUG_PRINT.println("Running self test...");
  for(uint8_t i = 0; i < TOTAL_ENGINES; i++){
    engineArray[i].handleCommand(CANMessageGenerator::createMoveToTargetMessage(5000, i+1));
    engineArray[i].handleCommand(CANMessageGenerator::createMoveToTargetMessage(-5000, i+1));
    engineArray[i].handleCommand(CANMessageGenerator::createMoveToTargetMessage(0, i+1));
    DEBUG_PRINT.printf("Queued command for motor %u\n", i);
  }
}

void stepAllMotors(){
  const uint32_t now = micros(); // grab time here so all motors stay in sync if ISR overlaps
  for(int i = 0; i < TOTAL_ENGINES; i++){ // step each stepper
    engineArray[i].stepMotor(now);
  }
}

void handleCommand(CANMessage& newMsg){
  DEBUG_PRINT.printf("Command for worker %u recieved\n", newMsg.AddressId);
  uint8_t engineId = newMsg.Data[0];
  
  if(engineId == ALL_MODULE_ID){   //pass to all engines
    for(uint8_t i = 0; i < TOTAL_ENGINES; i++){
      engineArray[i].handleCommand(newMsg);
    }
    return;
  }

  if(engineId >= 1 && engineId <= TOTAL_ENGINES){  //pick specific engine
    engineArray[engineId - 1].handleCommand(newMsg);
    return;
  }
}

void setup() {
  Serial.begin(115200);

  pinMode(PIN_STATUS_LED,OUTPUT);

  Serial.println("Setting up message engines");

  for(int i = 0; i < TOTAL_ENGINES; i++){ // begin each stepper
    engineArray[i].begin();
  }

  blink(1, 200, 200);
  
  Serial.println("Setting up CAN receiver");
  canBusReader.begin();
  canBusReader.addFilterId(0, MODULE_ID); // read messages meant for this module
  canBusReader.addFilterId(1, ALL_MODULE_ID); // read messages meant for "all modules"
  
  blink(1, 200, 200);

  // TIM2: fire every MIN_STEP_INTERVAL microseconds
  Serial.println("Setting up stepper interrupt timer");
  stepTimer = new HardwareTimer(TIM2);
  stepTimer->setOverflow(MIN_STEP_INTERVAL, MICROSEC_FORMAT); // 300ms = ~3333 Hz
  stepTimer->attachInterrupt(stepAllMotors);
  stepTimer->resume();
  
  blink(1, 200, 200); 

  Serial.println("Ready");
}

void loop() {
  getFreeRam(); // keep ram stats up to date

  while (Serial.available() > 0) {
      char c = (char)Serial.read(); // non blocking read (unlike readStringUntil which can cause motor stutter)
      if (c == '\n') {
          serialInputBuffer.trim();
          if (serialInputBuffer.equals("reset"))
            reset();
          if (serialInputBuffer.equals("test"))
            runSelfTest();
          if (serialInputBuffer.equals("stats"))
            printStats();
          serialInputBuffer = "";
      } else {
          serialInputBuffer += c;
      }
  }

  bool newData = canBusReader.read(msg);
  if(newData)
  {
    digitalWrite(PIN_STATUS_LED, HIGH); // flash on LED during receive

    switch(msg.Type){
      case CANMessageType::MoveToTarget:
      case CANMessageType::SetCurrentPositionToZero: // reset current position of stepper to 0
      case CANMessageType::EmergencyStop:
      case CANMessageType::CancelLastCommand:
      case CANMessageType::EmergencyStopReset:
        handleCommand(msg);
        break;
      case CANMessageType::ModuleStatusRequest:
        canBusWriter.write(systemMgmt.getModuleStatusResponse(msg, MODULE_ID));
        break;
      case CANMessageType::Stats:
        printStats();
        break;
      case CANMessageType::FullReset:  // reset microcontroller
        reset();
        break;
      default: 
        DEBUG_PRINT.print("Unknown message type ");
        DEBUG_PRINT.println(msg.Type);
    }

    digitalWrite(PIN_STATUS_LED, LOW); // endof recieve, LED off  
  }

  for(int i = 0; i < TOTAL_ENGINES; i++){ // step each stepper
    engineArray[i].run();
  }
}

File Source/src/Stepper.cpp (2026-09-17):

#include <Arduino.h>
#include <Stepper.h>
#include <SoftwareSerial.h>
#include <DataStructures.h>
#include <Constants.h>

Stepper::Stepper(uint8_t pinStep, uint8_t pinDirection, uint8_t pinEnable){
    this->_pinStep = pinStep;
    this->_pinDirection = pinDirection;
    this->_pinEnable = pinEnable;
    this->_stepsToGo = 0;
    this->_newTargetSet = false;
    this->_emergencyStop = false;
    this->_enabled = false;
    this->_currentPosition = 0;
    this->_targetPosition = 0;
    this-> _totalSteps = 0;
    this-> _previousMicros = 0;
    this-> _currentInterval = MIN_STEP_INTERVAL;
    this-> _currentDirection = _forwardSignal;
    this->_totalStepsTaken = 0;
}

void Stepper::begin(){
    DEBUG_PRINT.println("Setting motor pins");
    pinMode(_pinStep, OUTPUT);
    pinMode(_pinDirection, OUTPUT);
    pinMode(_pinEnable, OUTPUT);
    disable();
}

void Stepper::setTarget(int32_t targetPosition, uint8_t speed, bool hold){
    DEBUG_PRINT.printf("New target postition:%i\n", targetPosition);

    if(targetPosition == _currentPosition){
        return; // already at position
    }

    if (_targetPosition == targetPosition && _stepsToGo > 0) {
        return; 
    }

    this->_targetPosition = targetPosition;

    if (_targetPosition < _currentPosition) {
        setReverse();
        _totalSteps = (_currentPosition - _targetPosition);
    }
    else {
        setForward();
        _totalSteps = (_targetPosition - _currentPosition);
    }

    _newTargetSet = true;
    _stepsToGo = _totalSteps;

    // speed is treated as a percentage of max speed. e.g. speed 90 = 90% of max speed
    if(speed > _maxSpeed) {
        speed = _maxSpeed;
    }

    if(speed == 0) {
        speed = 1;  // treat speed zero as one to avoid division by zero below (which would cause a hard fault!)
    }

    _currentInterval = (MIN_STEP_INTERVAL * (uint32_t)_maxSpeed) / (uint32_t)speed;
}

bool Stepper::done(){
    return _stepsToGo == 0;
}

void Stepper::cancel(){
    _stepsToGo = 0;
    disable();
}

void Stepper::step(uint32_t now){
    if (done() || _emergencyStop)
        return;
    
    if (now - _previousMicros < _currentInterval)
        return;

    _previousMicros = now;

    if (!_enabled)
        enable();

    if (_currentDirection == _forwardSignal) // increment or decrement steps depending on direction
        _currentPosition++;
    else
        _currentPosition--;

    digitalWrite(_pinStep, HIGH);
    digitalWrite(_pinStep, LOW);

    _stepsToGo--;
    _totalStepsTaken++;

    if (done())
        disable();
}

void Stepper::setForward() {
    _currentDirection = _forwardSignal;
    digitalWrite(_pinDirection, _forwardSignal);
}

void Stepper::setReverse() {
    _currentDirection = _reverseSignal;
    digitalWrite(_pinDirection, _reverseSignal);
}

void Stepper::enable(){
    _enabled = true;
    digitalWrite(_pinEnable, LOW);
}

void Stepper::disable() {
    _enabled = false;
    digitalWrite(_pinEnable, HIGH);
}

void Stepper::emergencyStop() {
    DEBUG_PRINT.print("Emergency stop!");
    _emergencyStop = true;
    disable();
}

void Stepper::emergencyStopReset(){
    DEBUG_PRINT.print("Emergency stop reset");
    _emergencyStop = false;
    _stepsToGo = 0;
}

long Stepper::currentPosition(){
    return _currentPosition;
}

void Stepper::setCurrentPositionToZero(){
    _currentPosition = 0;
    _targetPosition = 0;
}
